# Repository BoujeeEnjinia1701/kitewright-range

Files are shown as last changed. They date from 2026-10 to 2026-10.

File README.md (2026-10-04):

# Kitewright Range

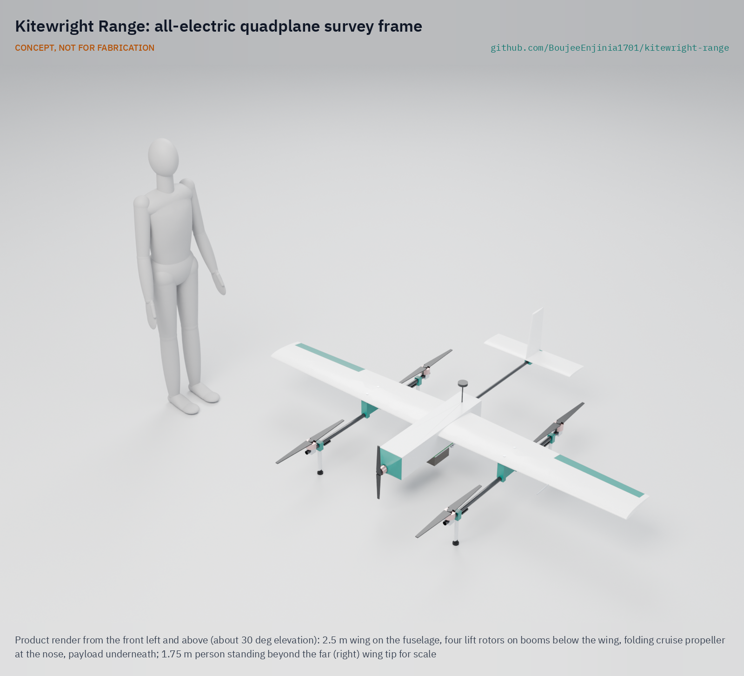
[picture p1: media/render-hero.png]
Kitewright Range: all-electric quadplane survey frame, product render


     

**Area:** Aerial robotics · **TRL:** 3 of 9 (proof of concept on paper; design constructable) · **Value-engineering target:** USD 5,000; estimated cost USD 4,314 (USD 686 under) · **Difficulty:** 4 of 5

An all-electric quadplane frame for the Kitewright family that takes off vertically and cruises on a fixed wing for long surveys.

[Problem](docs/01-problem.md) · [Precis](docs/02-concept.md) · [Requirements](docs/03-requirements.md) · [Calculations](docs/04-calcs/01-sizing.md) · [Prototype build plan](docs/05-build-plan.md) · [Design decisions](docs/06-design-decisions.md) · [General arrangement](cad/drawings/KWR-DWG-001.png) · [3D viewer](media/viewer.html)

CONCEPT, NOT FOR FABRICATION. On paper (KWR-CAL-001): 2.5 m span, 11.1 kg with a 1 kg payload, 52 % hover thrust margin at 5,000 m, and 33 min and 44 km on the wing with a 20 % reserve. Endurance and take-off mass miss their targets; Amish accepted both for the first prototype.

## Concept rationale

Kitewright Range is the long-reach frame of the Kitewright civilian drone family. It is an all-electric quadplane: four fixed lift rotors on two booms for vertical take-off and landing, a single fixed wing for cruise, and one electric cruise motor. It is not a tail-sitter and it has no tilting motors. It takes off from a moraine ridge or a lakeside camp, climbs, then flies on the wing, which needs far less power than hovering, so one battery covers a whole lake or snow basin.

It carries the Kitewright Core: an open PX4 or ArduPilot autopilot, the ColdCell power bus and the family's single payload mount (Pixhawk DS-014 style connector on a plain rail with a locking pin). Any Kitewright payload, including LakeWatch, fits without rework. Keeping the frame open and buildable means a state disaster agency, a university glaciology group or a mountain NGO can build, repair and adapt it, rather than wait for a vendor to support its altitude and climate.

## Burning platform

About 15 million people worldwide live in the path of potential glacial lake outburst floods, and 62% of them are in High Mountain Asia; since 1990 the number of glacial lakes has grown by 53% and their volume by 48% ([Taylor et al., Nature Communications, 2023](https://www.nature.com/articles/s41467-023-36033-x)). India has identified 189 high-risk glacial lakes out of about 7,500 in its Himalaya, but field teams can reach them only from June to September because they sit above 4,500 m, and only 15 had been visited when the national programme was approved ([ThePrint, 2024](https://theprint.in/india/govt-approves-rs-150-crore-for-glacial-lake-outburst-flood-risk-mitigation-programme-for-4-states/2232525/)).

Fixed-wing VTOL drones already do this kind of survey, but at a price and within limits that do not suit these users. The Quantum Systems Trinity Pro lists a 5,500 m service ceiling and a lowest operating temperature of -12 C ([Quantum Systems](https://quantum-systems.com/trinity-pro/)) and sells for about USD 23,790 ([Drone Nerds](https://www.dronenerds.com/products/quantum-systems-trinity-pro-americas)). Many Himalayan lakes lie at or above that ceiling, and air at 5,000 m in the standard atmosphere is already at -17.5 C with a density of 0.736 kg/m3, 60% of sea level ([Engineering ToolBox, US Standard Atmosphere](https://www.engineeringtoolbox.com/standard-atmosphere-d_604.html)). An open design lets users tune wing, rotors and batteries to their own altitude instead of accepting a vendor's envelope.

## Where it could be used

### By industry

| Industry | Use |
| --- | --- |
| Disaster risk management | Repeat surveys of high-risk glacial lakes and their moraine dams for state and national disaster agencies (with the LakeWatch payload) |
| Glaciology and climate research | Mapping of glacier snouts, lake area and snow cover over whole basins in one flight |
| Hydropower | Upstream hazard checks on lakes and valleys above run-of-river plants |
| Mountain search and rescue | Wide-area first sweep of a valley or glacier before a multirotor narrows the search |
| Water resources | Snowpack and melt surveys that feed seasonal water supply forecasts |

### By country or region

| Country or region | Why it matters there |
| --- | --- |
| India (Sikkim, Himachal Pradesh, Uttarakhand, Arunachal Pradesh) | The national programme covers 189 high-risk lakes, reachable on foot only from June to September above 4,500 m ([ThePrint, 2024](https://theprint.in/india/govt-approves-rs-150-crore-for-glacial-lake-outburst-flood-risk-mitigation-programme-for-4-states/2232525/)). |
| India (Kashmir Himalaya) | A 2026 inventory found 155 glacial lakes, five with very high outburst susceptibility threatening several thousand buildings, 15 major bridges and a hydropower project ([Journal of Glaciology, 2026](https://www.cambridge.org/core/journals/journal-of-glaciology/article/glacial-lake-outburst-flood-susceptibility-and-potential-downstream-implications-across-the-kas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)). |
| Pakistan (Gilgit-Baltistan and Khyber Pakhtunkhwa) | The UNDP GLOF-II project works across 24 valleys in 15 districts and serves more than 605,000 people ([UNDP](https://www.undp.org/pakistan/projects/scaling-glacial-lake-outburst-floods-risk-reduction-northern-pakistan-glof-ii-project)). |
| Nepal | The August 2024 Thame flood came from two lakes that do not appear to have been formally monitored beforehand ([Wikipedia, 2024 Thame flood](https://en.wikipedia.org/wiki/2024_Thame_flood)). |
| Peru (Cordillera Blanca) | Lake Palcacocha, whose 1941 outburst killed at least 1,600 people in Huaraz, had grown to 17.4 million m3 by 2016 and is still considered hazardous ([HESS, 2020](https://hess.copernicus.org/articles/24/93/2020/)). |

## What sparked the idea

In July 2018 the climber Rick Allen fell from an ice cliff while descending Broad Peak in the Karakoram and was missing for 36 hours. Bartek Bargiel, filming his brother's ski descent of K2, flew his drone over the slope, found Allen alive at about 7,500 m and guided a rescue team to him ([Explorersweb, 2018](https://explorersweb.com/rick-allen-found-alive-on-broad-peak/)). That flight showed what a small drone can do in the high mountains. It also showed the limit: a consumer multirotor has minutes of air time at that height. Kitewright Range asks what an open, long-reach frame could do for the same mountains, starting with the glacial lakes that threaten the valleys below.

## Problem

Surveys of glacial lakes and snowpack in the high Himalaya need a drone that takes off from rough ground and still covers many kilometres in thin, cold air. Commercial fixed-wing VTOL drones that can do this are closed and cost more than most mountain agencies and research groups can field.

Full problem statement: [docs/01-problem.md](docs/01-problem.md)

## Concept

An all-electric quadplane frame for the Kitewright family (separate fixed lift rotors, single fixed wing, electric cruise motor, not a tail-sitter) that takes off vertically and cruises for long survey flights such as glacial lakes and snowpack.

Full design precis: [docs/02-concept.md](docs/02-concept.md) · Requirements: [docs/03-requirements.md](docs/03-requirements.md)

## Key components

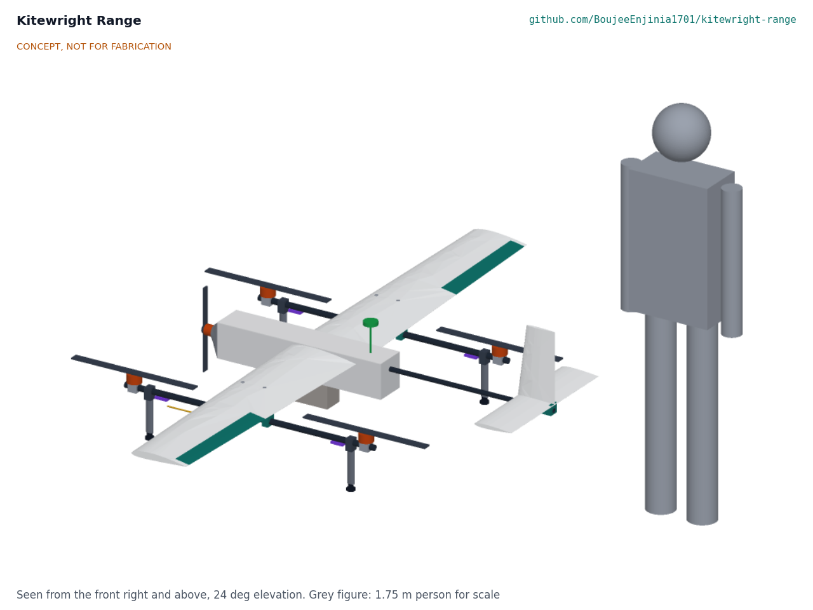
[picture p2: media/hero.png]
Concept overview with a 1.75 m person for scale


- Two-piece foam and glass wing, 2.5 m span, on a carbon joiner through a lite-ply fuselage
- Four fixed 22 in lift rotors on carbon booms, hung on printed pylons below the wing
- Tractor cruise motor with a folding propeller at the nose; conventional tail on a carbon boom
- Kitewright Core hung under the fuselage at the centre of gravity; two 6S Li-ion packs (648 Wh) with AS150 leads
- Four faired landing legs; heated pitot

## Building the prototype

The prototype is built from hot-wire cut foam skinned in glass, lite-ply, carbon tube and printed ASA parts, with bought motors, propellers and the Kitewright Core avionics. The build plan takes a capable model builder through thirteen made components and sixteen assembly steps, each with a picture. Powered work stops at five safety stops, and the lift propellers go on only once the aircraft is tied down inside a keep-out zone. It is a plan, not yet built; building to it is TRL 4 work.

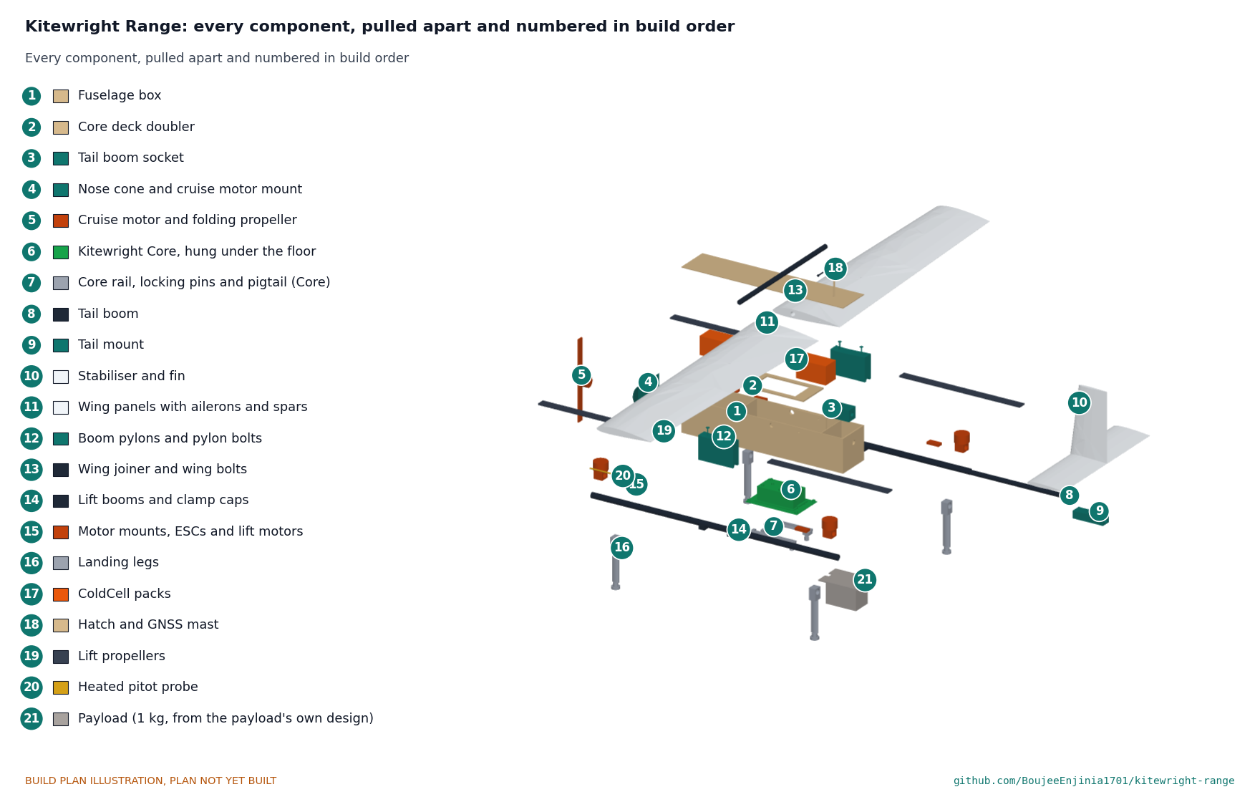
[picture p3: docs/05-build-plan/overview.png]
Every component, pulled apart and numbered in build order


## Safety

> Published as an open engineering reference, not certified aviation equipment.
>
> Civilian use only. Certification under FAA Part 107, EASA rules or India's Drone Rules 2021 is out of scope at this TRL and will be addressed if prototypes progress.
>
> Spinning lift and cruise propellers can cause serious injury; arming, pre-flight and keep-out procedures must be written before any powered test.
>
> Lithium battery packs carry fire risk, especially after a crash or cold charging; charge only between 0 and 45 °C pack temperature in a fire-resistant box, and follow ColdCell safety rules.
>
> Lift propellers are fitted only at the build plan's propeller safety stop; first hovers are tied down inside a 15 m keep-out zone with the arming plug and lockable arming switch in use.
>
> Loss of link or battery in thin air may cause a crash in remote terrain; failsafe return and landing behaviour must be set and tested.
>
> Fly only where local rules allow, away from people, aircraft and wildlife; high-altitude sites may lie in restricted border or protected areas.
>
> This design is published as an open engineering reference. It is not certified equipment.

## Repository layout

| Folder | Contents |
| --- | --- |
| `docs/` | Problem, concept, requirements, calculations and design decisions |
| `cad/src/` | build123d Python source, the source of truth for all geometry |
| `cad/step/`, `cad/stl/` | Exported models for FreeCAD, other CAD tools and printing |
| `cad/drawings/` | 2D sketches and dimensioned drawings |
| `bom/` | Bill of materials |
| `electronics/` | KiCad schematics and PCB layouts |
| `firmware/` | Microcontroller code |
| `media/` | Renders, perspectives and photos |
| `build-log/` | Dated prototyping notes |

## Documentation

Controlled documents follow the portfolio [documentation standard](.kit/STANDARDS.md). Each carries a document ID (KWR-PRC-001 for the precis), a version and a revision history. Branded PDFs are built with `python .kit/render.py` and attached to GitHub Releases when a document is tagged, for example `KWR-PRC-001/v1.0`.

## Credits

Designed by Amish Chadha at Design Molecule Labs. See [CONTRIBUTORS.md](CONTRIBUTORS.md) for roles. To cite this design, use [CITATION.cff](CITATION.cff) (GitHub shows it as "Cite this repository").

AI assistance (Claude) was used to accelerate prototype documentation and first-pass research. Design direction and all decisions are Amish Chadha's, recorded in this repository's decision records (`docs/decisions/`).

## Licenses

- **Hardware** (CAD, drawings, BOM, electronics): [CERN-OHL-S v2](LICENSE)
- **Software** (firmware, scripts, notebooks): [MIT](LICENSE-SOFTWARE)

A project of the [Design Molecule](https://designmolecule.com) lab.

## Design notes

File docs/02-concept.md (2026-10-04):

---
doc_id: KWR-PRC-001
title: Kitewright Range design precis
project: Kitewright Range
doc_type: Precis
version: "0.5"
status: Draft
date: '2026-10-04'
author: Amish Chadha
license: CERN-OHL-S-2.0
revisions:
- version: "0.1"
  date: '2026-09-30'
  author: Amish Chadha
  change: Initial scaffold
- version: "0.2"
  date: '2026-10-03'
  author: Amish Chadha
  change: TRL 2 precis with first-order numbers, components, design choices and safety (KWR-DDR-001)
- version: "0.3"
  date: '2026-10-03'
  author: Amish Chadha
  change: TRL 3 numbers from KWR-CAL-001 v0.2 on the constructable design (KWR-DDR-002)
- version: "0.4"
  date: '2026-10-03'
  author: Amish Chadha
  change: 'Numbers from KWR-CAL-001 v0.3 after Amish''s 2026-10-03 decisions (KWR-DDR-003; "i agree with all the 46 recommendations you provided. please proceed.")'
- version: "0.5"
  date: '2026-10-04'
  author: Amish Chadha
  change: 'Amish''s round-3 decision 10A (KWR-DDR-004); the Kitewright Core under the floor to the family envelope; numbers from KWR-CAL-001 v0.4'
---

# Kitewright Range design precis

An all-electric quadplane frame for the Kitewright family that takes off vertically and cruises on a fixed wing for long surveys.

## Summary

Kitewright Range is a 2.5 m span quadplane of 11.4 kg that lifts off on four fixed 22 in rotors, flies its survey on the wing and lands vertically again. On paper it hovers at 5,000 m with a 48.3 % thrust margin and flies 30.6 min and 41.5 km on the wing with a 1 kg payload and a 20 % reserve. It is built from hot-wire cut foam and glass, lite-ply, carbon tubes and printed parts with hobby tools, and costs an estimated USD 4,314 against a USD 5,000 value-engineering target. Endurance and take-off mass miss their targets; Amish accepted both for the first prototype on 2026-10-03 (KWR-DDR-003).

## How it works

A two-piece wing on a carbon joiner sits at the shoulder of a lite-ply fuselage. Under each wing a printed pylon holds a carbon boom with one lift motor 531 mm ahead of the centre of gravity and one 531 mm behind it, so the four rotors lift through the balance point; their discs run 77 mm below the wing-top plane. A tractor motor with a folding propeller at the nose drives the aircraft in cruise, and a conventional tail on a carbon boom steers it. The aircraft rises on the rotors, accelerates on the cruise motor to about 22 m/s, stops the rotors with their blades parked fore and aft, and flies a planned survey; then it slows, hovers and lands on four faired legs. The Kitewright Core hangs under the fuselage floor at the centre of gravity to the family mounting envelope, its lid up through the floor, and the payload hangs on its shoe from the Core's rail beneath it. Two ColdCell packs, one in the nose bay and one behind the Core's lid, feed the Core's power bus through AS150 plugs; the Core's GNSS receiver and antennas sit on the hatch. The flight code is stock PX4 quadplane firmware with published parameters (KWR-DDR-001, D1).

## Main components

Table 1. Components (numbers are BOM lines)

| # | Component | Made from, or bought | Role |
| --- | --- | --- | --- |
| 1, 2 | Fuselage box and hatch | Lite-ply and birch ply, glass outside | Carries the wing, packs, avionics, payload mount and tail |
| 3 | Nose cone and cruise motor mount | Printed ASA | Fairs the nose and holds the cruise motor on the thrust line |
| 4, 14, 15 | Tail boom socket, tail boom, tail mount | Printed ASA, carbon tube | Carries the tail 1 m behind the wing |
| 5, 6, 7, 8 | Wing panels with ailerons, spars, joiner, wing bolts | XPS foam and glass, carbon tubes, nylon bolts | Lift in cruise; panels come off for transport |
| 9, 10, 11, 12 | Boom pylons, pylon bolts, clamp caps, lift booms | Printed ASA, steel bolts, carbon tube | Hold the lift motors below the wing |
| 13 | Landing legs | Carbon rod, printed clamp and fairing, rubber foot | Stand the aircraft on rough ground |
| 16, 17 | Stabiliser with elevator, fin with rudder | XPS foam and glass | Pitch and yaw stability and control |
| 18 to 21 | Motor mounts, ESCs, 5215-class lift motors, 22 in propellers | Bought | Vertical take-off, hover and landing |
| 22, 23 | Cruise motor and ESC, 14 in folding propeller | Bought | Wing-borne flight |
| 24, 25 | Servos, heated pitot and airspeed sensor | Bought | Control surfaces; airspeed in cold and icing |
| 26, 27 | Kitewright Core with its payload rail | From the Kitewright Core, hung under the floor to the family envelope | Autopilot, GNSS, radios, payload interface |
| 28 | ColdCell packs, two | From the ColdCell design | 583 Wh of heated Li-ion energy |

## Numbers from the TRL 3 calculations

Table 2. Key figures (KWR-CAL-001 v0.2)

| Quantity | Value |
| --- | --- |
| Span, wing area, aspect ratio | 2.52 m, 0.709 m2, 8.9 |
| Take-off mass with 1 kg payload | 11.35 kg |
| Centre of gravity | 28.3 % of the 281 mm mean chord |
| Hover power and thrust margin at 5,000 m | 1,835 W; 48.3 % |
| Stall and cruise speed at 5,000 m | 18.1 m/s; 22.6 m/s |
| Lift-to-drag ratio in cruise | 7.2 |
| Cruise power from the packs | 676 W |
| Energy for cruise after hover, climb and reserve | 344 Wh |
| Endurance and range on the wing | 30.6 min; 41.5 km |
| Lowest structural safety factor | 2.7 (wing spar at 2.5 g) |
| Longest part for transport | 1,205 mm |
| Estimated cost | USD 4,314; value-engineering target USD 5,000 (USD 686 under) |

Assumptions are stated in KWR-CAL-001, Table 1. The most important are the maker-class thrust of the lift motors (68.7 N each at sea level for a 5215-class motor with a 22 x 7 in propeller, scaled by density) and a zero-lift drag coefficient of 0.083.

## Key design choices

All are decided under Amish's 2026-10-03 pre-approval and argued in KWR-DDR-001 and KWR-DDR-002; the propeller size and cells follow Amish's 2026-10-03 decisions (KWR-DDR-003):

- PX4 quadplane firmware, as the Kitewright Core (D1).
- Two-piece 2.5 m wing on a joiner, sized to the 1.3 m transport case (D2, C6).
- One set of 22 in lift propellers on 5215-class motors for every altitude band (D3, KWR-DDR-003).
- Tractor cruise motor at the nose with a folding propeller, conventional tail on a tail boom (D5, C1, C5).
- Lift booms on printed pylons 90 mm below the wing, motors centred on the centre of gravity (C2 to C4).
- Two ColdCell 6S3P Li-ion packs of 5.0 Ah cells either side of the joiner (D6, C7, KWR-DDR-003).
- Foam, glass, lite-ply, carbon tube and printed parts: buildable with hobby tools (D7).
- Staged powered tests, tie-downs and conservative failsafes (D9, D10).

## Patent design-arounds

From the preliminary patent, trademark and prior-art screen (not legal advice):

- All-electric, single fixed wing, fixed lift and cruise motors (no tilting thrust), to stay clear of US10343774B2 (tilting thrust, to about 2037).
- Lift booms on pylons below the wing with the rotor discs 77 mm below the wing-top plane, to stay clear of US9120560B1 (rotors even with the wing top surfaces, to 2033). The model checks this on every run.
- Layout kept distinct from US9242738B2 (Wisk, to about 2032); claims still to be read by an attorney before any sale.
- Not a tail-sitter, keeping clear of the Airbound tail-sitter noted in the family screen.

## Relationship to other lab projects

- Kitewright Core: autopilot, radios, GNSS, payload rail and power bus, used unchanged, to the Kitewright interface table of 2026-10-04 in `docs/REVIEW.md`.
- ColdCell: the two heated packs. Kitewright Lift shares the 6S bus.
- AltiRig: measures the lift motor and propeller thrust at 5,000 m density before any flight.
- LakeWatch: the first payload, within 1 kg on the Core mount.

## Safety

> **Safety:** Kitewright Range is published as an open engineering reference, not certified aviation equipment, for civilian use only. Certification under FAA Part 107, EASA rules or India's Drone Rules 2021 is out of scope at this TRL and will be addressed if prototypes progress.
>
> **Propellers.** Four 20 in lift propellers and a 14 in cruise propeller can cause serious injury. The lift propellers are fitted only at the build plan's propeller safety stop, never on the bench; a removable arming plug and a lockable arming switch keep the motors dead while anyone handles the aircraft; first hovers are tied down to ground anchors inside a 15 m keep-out zone (KWR-DDR-001, D9).
>
> **Lithium-ion packs.** Two packs hold about 580 Wh. Charge only between 0 and 45 °C pack temperature, in a fire-resistant box, never unattended; treat any pack from a crash as damaged and isolate it outdoors.
>
> **Loss of link or power in remote terrain.** Return to launch on the wing and land vertically; land in place at the reserve; fly inside a geofence (D10). Fly only where local rules allow, away from people, aircraft and wildlife; high-altitude sites may lie in restricted border or protected areas.
>
> **Structure.** The wing spar has the smallest margin (2.9 at 2.5 g). Proof-load the wing before the first flight (TRL 4).

## Open questions

None in this precis. Requirements not met or at risk are open decisions for Amish in the design decisions register (`docs/06-design-decisions.md`).

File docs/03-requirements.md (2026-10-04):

---
doc_id: KWR-REQ-001
title: Kitewright Range requirements
project: Kitewright Range
doc_type: Requirements
version: "0.5"
status: Draft
date: '2026-10-04'
author: Amish Chadha
license: CERN-OHL-S-2.0
revisions:
- version: "0.1"
  date: '2026-09-30'
  author: Amish Chadha
  change: Initial scaffold
- version: "0.2"
  date: '2026-10-03'
  author: Amish Chadha
  change: TRL 2 concept status for every requirement
- version: "0.3"
  date: '2026-10-03'
  author: Amish Chadha
  change: TRL 3 status from KWR-CAL-001 v0.2 on the constructable design; R10 cost stated against the value-engineering target
- version: "0.4"
  date: '2026-10-03'
  author: Amish Chadha
  change: 'Status from KWR-CAL-001 v0.3 after Amish''s 2026-10-03 decisions (KWR-DDR-003; Amish: "i agree with all the 46 recommendations you provided. please proceed."); targets unchanged; R2 and R7 shortfalls accepted for the first prototype'
- version: "0.5"
  date: '2026-10-04'
  author: Amish Chadha
  change: 'Status from KWR-CAL-001 v0.4 after Amish''s round-3 decision 10A (KWR-DDR-004; Amish: "For round 3, I agree with all your proposed recommendations"): the 0.99 kg Kitewright Core to the family envelope; targets unchanged'
---

# Kitewright Range requirements

Eight of the ten requirements are met on paper or by design (KWR-CAL-001 v0.4, Table 6). On 2026-10-04 Amish decided the Kitewright family reconciliation as recommended ("For round 3, I agree with all your proposed recommendations"; KWR-DDR-004): Range now carries the 0.99 kg Kitewright Core to the family mounting envelope, under the fuselage floor at the centre of gravity, with AS150 plugs on its packs. No requirement is restated. Endurance (R2) and take-off mass (R7) are not met. The targets below are unchanged. Amish decided the shortfalls on 2026-10-03 ("i agree with all the 46 recommendations you provided. please proceed."; KWR-DDR-003): 22 in propellers on 5215-class motors for R1, 5.0 Ah cells in the same two packs for R2 and R3, and the foam, glass and lite-ply airframe kept for the first prototype and weighed at TRL 4 for R7. No requirement is restated.

Table 1. Requirements and status at TRL 3

| ID | Requirement | Target | Verification (TRL 3 or later) | Status (KWR-CAL-001) |
| --- | --- | --- | --- | --- |
| R1 | Vertical take-off and landing at high altitude | Hover with at least 30% thrust margin at 0.74 kg/m3 air density (5,000 m) at maximum take-off mass | Lift motor and propeller thrust measured in AltiRig at 5,000 m density; margin calculated for the as-built mass | Met on paper: 48.3 % on maker-class thrust at 11.35 kg (22 in propellers, 5215-class motors); to measure in AltiRig |
| R2 | Cruise endurance at altitude | At least 45 min wing-borne flight at 5,000 m and -20 C with a 1 kg payload and 20% reserve (target) | Energy model checked against bench power data, then timed flight at a high site | **Not met:** 30.6 min with 5.0 Ah cells and the 0.99 kg Core under the floor; accepted for the first prototype (KWR-DDR-003) |
| R3 | Survey range | At least 40 km of survey track per flight at 5,000 m (target) | Flight log distance on a mapped survey pattern | Met on paper: 41.5 km |
| R4 | Payload capacity | 1.0 kg on the Kitewright mount within the centre of gravity range | Weigh and balance check; flight with a dummy payload | Met by design: the Core and its payload shoe under the CG, 28.3 % of the mean chord with or without the payload |
| R5 | Operating temperature | -20 to +40 C (-4 to +104 F) for all airframe electronics and servos | Cold chamber soak and function test of servos, motors and avionics | Met on paper by specification; cold ratings to confirm when parts are bought |
| R6 | Wind tolerance | Take off, transition and land in sustained wind of 10 m/s with gusts to 14 m/s | Flight tests with a logged anemometer at the launch site | Met on paper: cruise 22.6 m/s, stall 18.1 m/s, about 9 degrees of tilt holds a 14 m/s side gust in hover |
| R7 | Maximum take-off mass | No more than 8 kg including payload (target) | Weigh the complete aircraft | **Not met:** 11.35 kg; airframe kept and weighed at TRL 4 (KWR-DDR-003) |
| R8 | Transport | Packs into cases of no more than 1.3 m long; each carried load no more than 15 kg | Pack and measure; two-person carry trial | Met by design: longest part 1,205 mm; two cases of about 9 and 12.5 kg |
| R9 | Patent design-arounds held | Fixed motors, single wing, rotor discs clear of the wing-top plane in every revision | Design review checklist at each revision | Met by design: discs 77 mm below the wing-top plane, checked by the model |
| R10 | Open and buildable | All parts off the shelf or made with hobby tools; bill of materials at or below USD 5,000 | Costed BOM review; independent build by a second team | Met on paper: Value-engineering target: USD 5,000. Estimated cost of the constructable design: USD 4,314 (USD 686 under the target) |

## Requirements at risk or not met

- R2 and R7 pull against each other: more pack energy adds mass, and a lighter aircraft carries less energy. Amish accepted both shortfalls for the first prototype (KWR-DDR-003); with the reconciled Core no option inside the concept meets R2 on paper any more; a moulded carbon airframe with two 6S4P packs comes closest (42.5 min, USD 5,754) and is the second-prototype path (KWR-CAL-001 section H).
- R1 still rests on maker-class thrust that has not been measured at 5,000 m density; the 48.3 % margin leaves room for a thrust shortfall of about 12 % before the 30 % line.

## Assumptions

- Hover and cruise figures are at the ISA density for 5,000 m (0.736 kg/m3) with the ColdCell packs warmed before take-off.
- Stock PX4 quadplane firmware is enough; no custom flight control code is needed (KWR-DDR-001, D1).
- ColdCell packs deliver 95 % of their capacity at -20 °C once warmed (cross-repo assumption).
- Most survey missions can start from a site within 10 km of the target lake.

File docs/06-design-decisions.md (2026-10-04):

---
doc_id: KWR-DEC-001
title: Kitewright Range design decisions register
project: Kitewright Range
doc_type: Design decisions register
version: "0.3"
status: Draft
date: '2026-10-04'
author: Amish Chadha
license: CERN-OHL-S-2.0
revisions:
- version: "0.1"
  date: '2026-10-03'
  author: Amish Chadha
  change: Register opened at TRL 3; decisions made under the 2026-10-03 pre-approval; four requirement decisions proposed, awaiting Amish
- version: "0.2"
  date: '2026-10-03'
  author: Amish Chadha
  change: 'O1 to O4 decided by Amish on 2026-10-03 ("i agree with all the 46 recommendations you provided. please proceed."; 36B, 37A, 38A) and moved to Decisions made (KWR-DDR-003); Core power leads taken on under Core decision 33B'
- version: "0.3"
  date: '2026-10-04'
  author: Amish Chadha
  change: 'Round-3 decision 10A (Amish, 2026-10-04: "For round 3, I agree with all your proposed recommendations") recorded in Decisions made (KWR-DDR-004)'
---

# Kitewright Range design decisions register

Every design decision still to be made, and every decision made, in one place. Each decision is argued in full in its decision record under `docs/decisions/`, and the open ones in `docs/REVIEW.md` (TRL 3, Decisions for Amish); this register is the index Amish works from. The build plan (`docs/05-build-plan.md`) describes the design as it stands and does not list open decisions.

## Open decisions

None. Amish decided O1 to O4 on 2026-10-03 (KWR-DDR-003) and the Kitewright family reconciliation on 2026-10-04 (KWR-DDR-004); the design and build plan carry those decisions. R2 (30.6 min) and R7 (11.35 kg) remain not met, as accepted for the first prototype. Nothing in carrying out 10A needs Amish.

## To confirm when parts are bought

| # | What to confirm | Why it matters | Source |
| --- | --- | --- | --- |
| 1 | 5215-class lift motor thrust with a 22 x 7 in propeller at 0.736 kg/m3, measured in AltiRig | R1 rests on maker-class figures scaled by density; the 52.0 % margin allows about 14 % less thrust | KWR-CAL-001 C, KWR-DDR-003 |
| 2 | Cold ratings of the ESCs, servos, cruise motor ESC and pitot heater to -20 °C, or a cold soak test | R5 is met only by specification | KWR-REQ-001 |
| 3 | The joiner slides into both spar bores without play | The wing joint depends on it | KWR-DDR-002, C6 |
| 4 | The cruise motor's bolt circle and shaft length | They set the nose cone inserts and the propeller position | KWR-DDR-002, C5 |
| 5 | Kitewright Core avionics envelope (180 x 110 x 60 mm) and mass (0.78 kg with the mast); Core's own figure after its decision 33B is about 0.99 kg including the payload mount (Range carries 0.90 kg for the same items) | They set the front bay and the balance | Cross-repo assumption; `docs/REVIEW.md` cross-repo actions |
| 6 | ColdCell pack size (138 x 75 x 82 mm), mass (1.40 kg) with 5.0 Ah high-rate 21700 cells, and its lead (XT90 here, AS150 in the Core) | They set the battery bays, the energy and the balance | Cross-repo assumption, KWR-DDR-003 |
| 9 | Kitewright Core pad positions and grommets for the four 8 AWG power leads Range now supplies | Lead lengths and the solder joints at integration | Core decision 33B, KWR-DDR-003 |
| 7 | Payload mount plate (160 x 80 x 12 mm) and its four M4 holes | They set the floor inserts | Cross-repo assumption |
| 8 | Transport cases with at least 1,250 mm inside | The wing panel is 1,205 mm with its root fittings | KWR-CAL-001 F |

## Value engineering

Value-engineering target: USD 5,000 (a hypothetical control target, not a limit). Estimated cost of the constructable design: USD 4,293 (USD 707 under the target). Main cost drivers and savings worth trying:

- The largest lines are the Kitewright Core avionics share (USD 900, assumed), the two ColdCell packs of 5.0 Ah cells (USD 700), the four 5215-class lift motors (USD 600), the two transport cases (USD 360) and the four lift ESCs (USD 180).
- The 2026-10-03 decisions added USD 348: motors USD 120, propellers USD 40, cells USD 120, boom tubes USD 8 and the Core power leads USD 60 (moved from the Core's bill).
- Savings worth trying: soft padded bags in place of hard cases for vehicle transport (about USD 200); four-in-one ESC boards are lighter but would move power wiring into the fuselage, so they are not recommended.

## Decisions made

| Date | Decision | Decided by | Record |
| --- | --- | --- | --- |
| 2026-10-03 | TRL 2 review decisions D1 to D10: PX4; 2.5 m two-piece wing; one 20 in propeller set; winch on Lift; nose tractor and tail boom; two ColdCell 6S3P packs; foam, ply and printed build; Sikkim State Disaster Management Authority as first co-design candidate (not agreed); staged powered tests; conservative failsafes | Amish: "start with the first 14 repos from the list of 29 projects. I pre-approve the batch runs along with any recommendations you come up with. I also accept any cost overruns or variations from the assumed scope cost." and "Proceed with the remaining 15 scaffolds" | KWR-DDR-001 |
| 2026-10-03 | Design for construction C1 to C13: tail boom, pylons, boom spacing, motors on the centre of gravity, nose tractor, joiner and wing bolts, fuselage bays, landing legs, wing conduits, payload mount, tail joint, hatch, pitot | Amish, same pre-approval | KWR-DDR-002 |
| 2026-10-03 | O1 (36B), R1: 22 in propellers on 5215-class motors, booms 50 mm longer and 20 mm further out; hover margin 52.0 % | Amish: "i agree with all the 46 recommendations you provided. please proceed." | KWR-DDR-003 |
| 2026-10-03 | O2 and O3 (37A), R2 and R3: 5.0 Ah cells in the same two 6S3P packs; 32.9 min and 44.3 km with O1-B | Amish, same words | KWR-DDR-003 |
| 2026-10-03 | O4 (38A), R7: keep the foam, glass and lite-ply airframe and weigh it at TRL 4; 11.07 kg | Amish, same words | KWR-DDR-003 |
| 2026-10-03 | Range supplies the four Kitewright Core power leads with AS150 plugs (Core decision 33B) | Amish, same words (Core decision 33B) | KWR-DDR-003 |
| 2026-10-04 | Round-3 decision 10A: AS150 plugs on the packs (XT90 before); the Kitewright Core to the one family mounting envelope, the Core's drawing the reference: hung under the floor at the centre of gravity on four M4 (220 x 130 mm) in a 6 mm birch doubler, lid up through a 200 x 112 mm opening, fuselage 156 mm wide (150 inside), packs moved to the nose bay and behind the lid, rear bulkhead at 645 mm, GNSS and antennas on the hatch; Range recomputed with the 0.99 kg Core (30.6 min, 41.5 km, 48.3 %); the Kitewright interface table in `docs/REVIEW.md` | Amish: "For round 3, I agree with all your proposed recommendations" | KWR-DDR-004 |

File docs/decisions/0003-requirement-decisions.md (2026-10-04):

---
doc_id: KWR-DDR-003
title: Kitewright Range requirement decisions (R1, R2, R3, R7) and Core power leads
project: Kitewright Range
doc_type: Design decision record
version: "0.1"
status: Draft
date: '2026-10-03'
author: Amish Chadha
license: CERN-OHL-S-2.0
revisions:
- version: "0.1"
  date: '2026-10-03'
  author: Amish Chadha
  change: Amish's requirement decisions 36B, 37A and 38A carried out, with the Kitewright Core power leads taken on under Core decision 33B
---

# 0003: Requirement decisions on hover margin, endurance, range and mass

- **Date:** 2026-10-03
- **Status:** accepted
- **Decided by:** Amish Chadha, 2026-10-03, accepting every recommendation put to him in the second round of requirement decisions: "i agree with all the 46 recommendations you provided. please proceed." For Kitewright Range: 36B (R1, register O1), 37A (R2 and R3, register O2 and O3) and 38A (R7, register O4). Kitewright Core decision 33B, decided in the same words, moves the Core's power leads to each frame.

> **Safety:** The 22 in lift propellers are larger and the motors stronger: fit them only at the propeller safety stop of the build plan, with the arming plug out and the lockable switch locked, and hold the 15 m keep-out zone for tied first hovers (KWR-DDR-001, D9). The 5.0 Ah cells change nothing in the ColdCell pack's charging rules: charge between 0 and 45 °C pack temperature in a fire-resistant box. Soldering the 8 AWG Core power leads needs a 100 W iron; hold the wire with pliers, and check polarity and the opposite-gender plugs with a meter before any pack is connected.

## Context

At TRL 3 (KWR-CAL-001 v0.2) four requirements were at risk or not met: R1 hover thrust margin (31.8 % on unmeasured maker-class thrust), R2 endurance (31.0 min against 45 min), R3 survey range (40.9 km against 40 km) and R7 take-off mass (10.58 kg against 8 kg). Each was put to Amish in `docs/REVIEW.md` as state, options and a recommendation, and listed as O1 to O4 in `docs/06-design-decisions.md`.

In parallel, Kitewright Core decision 33B lightens the core by moving its four 8 AWG power leads and AS150 plugs out of the core and into each frame's harness, so Range now supplies its own.

## Options considered

- **R1 (decision 36, O1):** A: keep 20 in propellers on 5212-class motors. B (chosen): 22 in propellers on 5215-class motors, booms 50 mm longer and 20 mm further out. C: keep A and change only if AltiRig measures under the target.
- **R2 and R3 (decision 37, O2 and O3):** A (chosen): two 6S3P packs of 5.0 Ah cells. B: two 6S4P packs. C: moulded carbon airframe with two 6S4P packs. Range option A was the same cell change; with 36B it is the combination v0.2 listed as option B for R3.
- **R7 (decision 38, O4):** A (chosen): keep the foam, glass and lite-ply airframe and weigh it at TRL 4. B: moulded carbon wing, tail and fuselage. C: fly one pack.

## Decision

1. **36B.** Lift motors are 5215-class (about 285 g, 62 mm can, at least 7.0 kgf maker static thrust with a 22 x 7 in propeller on 6S, USD 150 each) on mounts with a top plate at least 64 mm across; lift propellers are 22 x 7 in carbon (about 55 g, USD 50 each). The booms move from 470 to 490 mm from the centre line and the motors from 506 to 531 mm ahead of and behind the centre of gravity, so each boom is 1,142 mm (cut from a 1,200 mm tube) in place of 1,092 mm.
2. **37A.** Both ColdCell packs stay 6S3P, 138 x 75 x 82 mm and 1.40 kg, with high-rate 21700 cells of 5.0 Ah: 324 Wh each (USD 350 each, USD 60 more).
3. **38A.** The airframe is unchanged. R7 stays not met for the first prototype; the aircraft is weighed at TRL 4 and the target is reviewed against the first site's rules before a second prototype.
4. **Core power leads (Core 33B).** Range supplies the four 8 AWG power leads with AS150 plugs (two pack inputs, two frame outputs, opposite genders), soldered to the Core's pads at integration: BOM line 33, about 124 g, USD 60 (the Core's former BOM line 21).

No requirement target is restated.

## Results (KWR-CAL-001 v0.3)

| Requirement | Before | After | Status |
| --- | --- | --- | --- |
| R1, hover thrust margin at 5,000 m (at least 30 %) | 31.8 % at 10.58 kg | 52.0 % at 11.07 kg | Met on paper; thrust to measure in AltiRig |
| R2, endurance (at least 45 min) | 31.0 min | 32.9 min | Not met; accepted for the first prototype |
| R3, survey range (at least 40 km) | 40.9 km | 44.3 km | Met on paper |
| R7, take-off mass (no more than 8 kg) | 10.58 kg | 11.07 kg | Not met; weighed at TRL 4 |
| R9, discs below the wing-top plane (at least 70 mm) | 81 mm | 77 mm | Met by design |
| R10, cost | USD 3,945 | USD 4,293 | Met on paper |

The recommendations quoted 53.3 % and 35.6 min, 46.8 km for the options taken one at a time. Taken together, and with the Core power leads (0.12 kg) and slightly more drag from the larger motors, the figures are 52.0 %, 32.9 min and 44.3 km.

Value-engineering target: USD 5,000. Estimated cost of the constructable design: USD 4,293 (USD 707 under the target). Take-off mass 11.07 kg with the 1 kg payload (0.49 kg more: motors and propellers 0.36 kg, booms 0.01 kg, Core power leads 0.12 kg).

## Consequences

- The model (`cad/src/model.py`) gained three checks for the larger discs: at least 50 mm from the fuselage side (141 mm), at least 50 mm from the stabiliser (110 mm), and a motor no wider than its mount plate. All 72 solids in 48 parts pass; the lift and cruise discs are 33 mm apart (rule 20 mm).
- STEP and STL, the general arrangement (KWR-DWG-001 Rev P3), the concept blueprint (KWR-DWG-010 Rev P3), the concept media, the making sketches of the wing panel, pylon and boom, and the build plan overview, joints and steps are regenerated.
- The R2 and R7 shortfalls remain. A moulded carbon airframe with two 6S4P packs meets R2 on paper (45.6 min, USD 5,733) and stays the second-prototype path.
- Cross-repo: the ColdCell pack format now uses 5.0 Ah cells; Kitewright Core no longer supplies the power leads.

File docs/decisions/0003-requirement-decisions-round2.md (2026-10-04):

---
doc_id: KWR-DDR-003
title: Kitewright Range requirement decisions, round 2
project: Kitewright Range
doc_type: Design decision record
version: "0.1"
status: Draft
date: '2026-10-03'
author: Amish Chadha
license: CERN-OHL-S-2.0
revisions:
- version: "0.1"
  date: '2026-10-03'
  author: Amish Chadha
  change: Decisions O1 to O4 on the requirements not met or at risk, decided by Amish on 2026-10-03 and carried into the model, calculations, BOM and build plan
---

# 0003: Requirement decisions, round 2

- **Date:** 2026-10-03
- **Status:** Decided. Decided by Amish Chadha, 2026-10-03: "i approve all of the 47 recommendations provided by you. Execute them." Each decision below is the recommendation as worded in `docs/06-design-decisions.md` (KWR-DEC-001 v0.1), including its conditions.

## Context

KWR-CAL-001 v0.2 left four requirements not met or at risk on the constructable design: hover thrust margin (R1, 31.8 % on unmeasured maker-class thrust), endurance (R2, 31.0 min), survey range (R3, 40.9 km, a 2 % margin) and take-off mass (R7, 10.58 kg). They were set out as O1 to O4, Proposed, awaiting Amish, with options and a recommendation each. O3 was linked to the others: its recommendation was A, decided together with O2, and B if O1-B was chosen.

## Decision

Table 1. Decisions

| # | Requirement | Option chosen | Effect on the design (KWR-CAL-001 v0.3) | Condition |
| --- | --- | --- | --- | --- |
| O1 | R1, hover thrust margin | **B:** 22 in propellers on 5215-class motors | Booms 20 mm further out (490 mm from the centre line) and 50 mm longer (1,142 mm); motors 531 mm ahead of and behind the centre of gravity; margin 31.8 % to 53.4 %; +0.39 kg; +USD 160 (motors, propellers, longer boom tubes) | Thrust is a maker-class estimate (7.0 kgf at sea level) until AltiRig measures it at 0.736 kg/m3 (TRL 4) |
| O2 | R2, endurance | **A:** two 6S3P packs of 5.0 Ah high-rate 21700 cells | Pack energy 583 Wh to 648 Wh, pack mass unchanged; +USD 120. With O1-B the endurance is 33.6 min (35.6 min with O2-A alone) | R2 is still not met; C (moulded carbon airframe with 6S4P packs) was named as the path for a second prototype once the first one's drag and mass are measured |
| O3 | R3, survey range | **B**, the combined effect: the recommendation was A, decided together with O2, becoming B because O1-B is chosen | 45.0 km (the option stated about 45.0 km); +USD 280 and +0.40 kg combined with O1-B and O2-A (calculated: +USD 280, +0.39 kg). No change of its own: it is the result of O1-B with O2-A | None beyond those of O1 and O2 |
| O4 | R7, take-off mass | **A:** keep the foam, glass and lite-ply airframe | No change to the airframe. Take-off mass is now 10.97 kg (10.58 kg before O1-B) | The first prototype is weighed at TRL 4; R7 stays not met. If the 8 kg target reflects a regulatory class at the first site, that site's rules set the target before the second prototype |

## Consequences

- Requirement status (KWR-REQ-001 v0.4): R1 at risk to met on paper; R2 not met (31.0 to 33.6 min); R3 at risk to met on paper (45.0 km, a 12 % margin); R7 not met (10.58 to 10.97 kg), kept by decision. No requirement was restated.
- Estimated cost: USD 3,945 to USD 4,225 against the USD 5,000 value-engineering target (USD 775 under). `budget_usd` in `project.yaml` is the value-engineering target and stays at USD 5,000.
- The wing spar's safety factor falls from 2.9 to 2.8 at 2.5 g with the heavier aircraft; the lift boom's from 10.8 to 8.4 and the pylon bolts' from 12.5 to 9.9 with the larger thrust. All stay above 2.
- Geometry: rotor discs 78 mm below the wing-top plane (rule 70 mm), lift discs 33 mm clear of the cruise propeller disc, rear discs 110 mm ahead of the stabiliser. The model's constructability checks pass (72 solids in 48 parts).
- Regenerated from the changed model: STEP and STL, general arrangement KWR-DWG-001 Rev P3, making sketches KWR-DWG-105, 106, 108 and 109 at Rev P2, the build plan pictures, the concept media with blueprint KWR-DWG-010 Rev P3, and `media/model.glb`.
- The remaining endurance shortfall (R2) is a new open decision, O5, in `docs/06-design-decisions.md`.
- Cross-repo: ColdCell needs the 5.0 Ah cell variant of its 6S3P pack; AltiRig's first job is now the 5215-class motor with a 22 in propeller.
- Following Kitewright Core decision 17 B (not a decision of this record), the Core's four 8 AWG power leads with AS150 plugs (two pack inputs, two frame outputs) are now part of Range's harness, BOM line 29: +USD 60 and +0.124 kg, priced as on Kitewright Lift. With them the take-off mass is 11.09 kg (R7 not met), hover margin 51.7 %, endurance 32.9 min, range 44.4 km and the estimated cost USD 4,285 (KWR-CAL-001 v0.4).

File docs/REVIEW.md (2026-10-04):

# Review note: Kitewright Range

## Session 2026-09-30: scaffolded

### What was done

- Repository created from kit 1.6.0 at TRL 1, target TRL 2.
- `docs/01-problem.md` (KWR-PRB-001 v0.1): problem with cited evidence, users, environment, constraints, prior work, open questions.
- `docs/02-concept.md` (KWR-PRC-001 v0.1): how it works, components, patent design-arounds, shared blocks, safety.
- `docs/03-requirements.md` (KWR-REQ-001 v0.1): 10 proposed requirements.
- `README.md` with concept rationale, burning platform, where it could be used, and what sparked the idea.

### Next

- Run `/populate` to bring the repo to a strong TRL 2 with concept media.

## Session 2026-10-03: TRL 2 (populate, under Amish's pre-approval)

Run as the first half of `/to-trl3` on kit 1.7.0, under Amish's 2026-10-03 instructions: "start with the first 14 repos from the list of 29 projects. I pre-approve the batch runs along with any recommendations you come up with. I also accept any cost overruns or variations from the assumed scope cost." and, for Batch 2, "Proceed with the remaining 15 scaffolds".

### What was done

- Kit 1.7.0 installed (`.kit/`, `.claude/commands/`); root `CLAUDE.md` replaced from `.kit/CLAUDE.md`.
- `docs/01-problem.md` (KWR-PRB-001 v0.2): open questions answered, value-engineering wording, co-design candidate, safety note.
- `docs/03-requirements.md` (KWR-REQ-001 v0.2): concept status for each requirement (targets unchanged).
- `docs/02-concept.md` (KWR-PRC-001 v0.2): how it works, components, first-order numbers, design choices, safety.
- `docs/decisions/0001-trl2-review-decisions.md` (KWR-DDR-001): D1 to D10.
- Massing model, concept media and BOM, then carried straight into TRL 3 (below), so the TRL 2 media were superseded by the TRL 3 set in the same session.

### Results at TRL 2

- The TRL 2 concept was carried straight into the TRL 3 calculations in the same session; all figures are the TRL 3 figures below.

### Decisions made under the pre-approval (KWR-DDR-001)

- D1 PX4 quadplane firmware; D2 2.5 m two-piece wing; D3 one 20 in propeller set; D4 the LakeWatch winch belongs on Kitewright Lift; D5 nose tractor and tail boom; D6 two ColdCell 6S3P Li-ion packs; D7 foam, glass, lite-ply and printed build; D8 Sikkim State Disaster Management Authority as the first co-design candidate to approach (not agreed), a university glaciology group second; D9 staged powered tests with tie-downs, keep-out zone, arming plug and lockable switch (conservative; relax the tie-down only after 10 logged tied hovers with no fault); D10 return to launch and land vertically on loss of link or low battery, land in place at the reserve, geofence.

### Safety concerns

- Large propellers, lithium-ion packs and a crash in remote terrain; covered in the precis safety section and D9, D10.

## Session 2026-10-03: TRL 3 (advance, design for construction, build plan)

### What was done

- `docs/04-calcs/01-sizing.md` (KWR-CAL-001 v0.2) with `docs/04-calcs/sizing.py` and `results.csv`: mass and balance from the model, drag build-up, hover at 5,000 m, energy, structure, geometry rules, cost, options for every shortfall, and a results table against every requirement.
- `cad/src/model.py`: parametric build123d model of the constructable design with constructability checks (72 solids in 48 parts: no overlaps, nothing floating, rotor discs at least 70 mm below the wing-top plane, lift and cruise discs apart, every part shorter than a 1.3 m case). STEP in `cad/step/` (assembly, fuselage, right wing panel, right boom pylon, landing leg parts, tail) and STL of the printed parts in `cad/stl/`.
- `cad/src/sheets.py`: general arrangement KWR-DWG-001 at Rev P2 (P1 preliminary GA, P2 design for construction).
- `bom/bom.csv`: 32 lines, every one priced, with a supplier type.
- `cad/src/concept_media.py`: hero, cutaway, exploded view with BOM numbers, blueprint KWR-DWG-010 Rev P2, glTF viewer (`media/model.glb`, about 1 MB, coarse tessellation) and energy flow per flight.
- `docs/decisions/0002-design-for-construction.md` (KWR-DDR-002): changes C1 to C13.
- `cad/src/build_plan_media.py`: overview, 13 making sketches (KWR-DWG-101 to 113), 8 joint close-ups, 16 assembly steps.
- `docs/05-build-plan.md` (KWR-BLD-001), `docs/06-design-decisions.md` (KWR-DEC-001).
- `cad/src/product_model.py` (appearance model, hero, exploded and detail views) and render scenes exported to `/home/claude/renders/kitewright-range/` for the photoreal renders on Amish's Mac.
- `docs/02-concept.md` v0.3 and `docs/03-requirements.md` v0.3 brought to the TRL 3 figures; `project.yaml` at TRL 3, target 3, `design_state: constructable`; README leads with `media/render-hero.png` (made on the Mac) and has the build plan link and "Building the prototype".

### Results (KWR-CAL-001 v0.2)

| Quantity | Value |
| --- | --- |
| Take-off mass with 1 kg payload | 10.58 kg (packs 2.80 kg) |
| Centre of gravity | 28.4 % of the mean chord, unchanged by the payload |
| Hover at 5,000 m | 1,815 W; thrust margin 31.8 % |
| Cruise | 21.9 m/s, L/D 7.5, 585 W |
| Endurance and range on the wing | 31.0 min, 40.9 km with a 20 % reserve |
| Lowest structural safety factor | 2.9, wing spar at 2.5 g |
| Cost | Value-engineering target: USD 5,000. Estimated cost of the constructable design: USD 3,945 (USD 1,055 under the target) |

### Requirements not met or at risk

- R1 hover thrust margin: at risk (31.8 %, on maker-class thrust not yet measured).
- R2 endurance: not met (31.0 min).
- R3 survey range: at risk (40.9 km).
- R7 take-off mass: not met (10.58 kg).
- All others met on paper or by design; R5 depends on cold ratings to confirm when parts are bought.

### Decisions for Amish

Each item is **Proposed, awaiting Amish**, and is listed in `docs/06-design-decisions.md` under Open decisions. Figures are from KWR-CAL-001 v0.2, Table 5; the design stays as it is until Amish decides.

**O1. R1 hover thrust margin.** State: 31.8 % at 10.58 kg and 0.736 kg/m3, against the requirement's margin; cause: it rests on a maker-class 5.8 kgf sea-level thrust scaled by density, with no measured data, so a few percent of thrust shortfall or mass growth erases it.
- A: keep 20 in propellers on 5212-class motors. Margin 31.8 %; no cost or mass change.
- B: 22 in propellers on 5215-class motors. Margin 53.3 %; +USD 160; +0.40 kg; endurance -1.7 min, range -1.7 km; booms 50 mm longer and 20 mm further out to keep the disc clearances.
- C: keep A now and switch to B only if AltiRig measures less than the requirement. No change now; the risk moves to the test.
- **Recommendation: B.** Hover authority at 5,000 m is the aircraft's safety margin in gusts, so the conservative choice applies; the cost is small and combined with O2-A the endurance still improves on today's design.

**O2. R2 endurance.** State: 31.0 min against the requirement; cause: 583 Wh in 2.80 kg of packs drives a 10.6 kg aircraft with a zero-lift drag coefficient of 0.077 (stopped lift motors and an external payload), needing 585 W in cruise.
- A: two 6S3P packs of 5.0 Ah high-rate 21700 cells. 35.6 min; +USD 120; no mass change; hover margin unchanged.
- B: two 6S4P packs. 38.9 min; +USD 190; +0.88 kg; hover margin falls to 21.7 % (R1 then fails).
- C: moulded carbon wing, tail and fuselage with two 6S4P packs. 43.3 min; +USD 1,390; +0.19 kg; margin 29.4 %; USD 5,335 in all.
- **Recommendation: A** for the first prototype; C is the path for a second prototype once the first one's drag and mass are measured.

**O3. R3 survey range.** State: 40.9 km against the requirement, a 2 % margin; cause: range follows endurance at 21.9 m/s.
- A: 5.0 Ah cells as O2-A. 46.8 km; +USD 120; no mass change.
- B: A together with O1-B. 45.0 km; +USD 280; +0.40 kg.
- C: keep as is. 40.9 km; no change.
- **Recommendation: A**, decided together with O2 (B if O1-B is chosen).

**O4. R7 take-off mass.** State: 10.58 kg against the requirement; cause: ColdCell packs 2.80 kg, lift system with mounts 1.32 kg, payload 1.00 kg and Core avionics 0.78 kg leave 4.7 kg for an airframe built with hobby methods.
- A: keep the foam, glass and lite-ply airframe. 10.58 kg; no change.
- B: moulded carbon wing, tail and fuselage. 9.89 kg; +USD 1,200 (USD 5,145 in all, USD 145 over the value-engineering target); endurance +4.1 min.
- C: fly with one pack. 9.18 kg; endurance 15.0 min, which fails R2 and R3 by far.
- **Recommendation: A** for the first prototype, weighed at TRL 4. No option inside the concept reaches the target without giving up endurance; if the target reflects a regulatory class at the first site, that site's rules should set the target before the second prototype.

### Decisions made under the pre-approval

- KWR-DDR-001 D1 to D10 (TRL 2 review) and KWR-DDR-002 C1 to C13 (design for construction), both dated 2026-10-03 and recorded in `docs/06-design-decisions.md` with Amish's words.

### Design changes made for construction (KWR-DDR-002)

- C1 tail on its own carbon tail boom, not on the lift booms.
- C2 lift booms on printed pylons through-bolted under the wing with clamp caps; rotor discs 81 mm below the wing-top plane.
- C3 booms 470 mm out, 38 mm clear of the cruise propeller disc.
- C4 lift motors 506 mm ahead of and behind the centre of gravity.
- C5 tractor cruise motor at the nose on a printed cone, folding propeller.
- C6 two wing panels on a carbon joiner, nylon wing bolts, straight spar at 30 % chord.
- C7 lite-ply fuselage box with packs either side of the joiner and Core avionics in front.
- C8 four faired landing legs.
- C9 wing wiring conduits and root plugs.
- C10 payload mount on the centre of gravity.
- C11 printed tail socket and tail mount.
- C12 hatch with GNSS mast and arming switch.
- C13 heated pitot in the left wing.

### Build plan findings

- The concept's booms could not carry the tail and still fit the 1.3 m case (C1).
- Without a pylon depth rule, the rotor discs would sit near the wing plane the design-around avoids; the model now checks the 70 mm rule on every run.
- The boom spacing first tried (450 mm) put the front lift discs within 18 mm of the cruise propeller disc; 470 mm gives 38 mm.
- Weighing every made part from the model raised the take-off mass from the TRL 2 estimate to 10.58 kg; printed parts are weighed as walls plus infill, and the pylons were shortened to 160 mm to save 0.2 kg.
- The tightest structural margin is the wing spar (2.9 at 2.5 g); the build plan's safety stop 4 requires a proof load before free flight (TRL 4).

### Appearance model (product_model.py)

- Every part comes from `model.py`. The only difference: the lift and cruise propellers are drawn as tapered blades in place of the model's flat blade envelopes of the same diameter. Proposed, awaiting Amish (appearance only).
- The detail view should be rendered with `--focus` on the left front lift motor and pylon.
- Hero framing: the 1.75 m person stands beyond the right wing tip, behind the aircraft as seen from the hero camera, so it never stands between the camera and the product.

### Safety concerns

- Four 20 in lift propellers and a 14 in cruise propeller: fitted only at the propeller safety stop, arming plug and lockable switch, tied first hovers in a 15 m keep-out zone (D9).
- About 580 Wh of Li-ion: charge between 0 and 45 °C pack temperature in a fire-resistant box; crash-damaged packs isolated outdoors.
- Loss of link or power in remote terrain: return on the wing and land vertically, land in place at the reserve, geofence (D10).
- Wing spar margin 2.9 at 2.5 g: proof-load before free flight.
- High-altitude sites may lie in restricted border or protected areas; fly only with the site partner's permissions.

### Cross-repo actions (sibling repos not edited)

Kitewright Core and Kitewright Lift are being done in parallel; these shared-interface assumptions are used here and should be confirmed in those repos:

1. **Kitewright Core, firmware:** PX4 (VTOL standard quadplane) as the family reference, with a Range parameter set at sea level, 3,000 m and 5,000 m.
2. **Kitewright Core, avionics envelope:** 180 x 110 x 60 mm, 0.70 kg, plus a GNSS mast of 0.08 kg through the hatch; USD 900 as Range's share in the BOM.
3. **Kitewright Core, payload mount:** a 160 x 80 x 12 mm plate with a rail, locking pin and DS-014 connector, 0.12 kg, fixed by four M4 bolts; payload envelope 150 x 90 x 100 mm and 1 kg with its centre of gravity under the mount centre; connector lead through the fuselage floor.
4. **Kitewright Core, power:** a 6S bus (21.6 V nominal Li-ion) taking two packs in parallel, carrying about 85 A in hover at 5,000 m (about 42 A per pack); an arming plug in the main lead and a lockable arming switch.
5. **ColdCell:** a 6S3P pack of 4.5 Ah 21700 cells, 291.6 Wh, 1.40 kg, 138 x 75 x 82 mm, XT90 lead, film heater and BMS thermostat holding the cells above 15 °C, 95 % usable at -20 °C ambient once warmed; a 5.0 Ah cell variant is proposed in O2.
6. **Kitewright Lift:** shares the 6S bus voltage, the Core mount and the ColdCell pack format; the LakeWatch sampling winch is assigned to Lift (D4).
7. **AltiRig:** first job is the thrust of a 5212-class motor with a 20 x 6.5 in propeller (and the 5215-class with 22 in, for O1) at 0.736 kg/m3.

### Recommended next step

- Amish decides O1 to O4. Then render the hero, exploded and detail views on the Mac from the exported scenes, make the cards, and run the release gate. The design is ready for TRL 4 parts purchase and AltiRig thrust tests once O1 is settled; that is a recommendation only, not started.

## 2026-10-03: photoreal renders

Rendered with Blender Cycles on Amish's Mac from `cad/src/product_model.py`; captioned with `.kit/photo_caption.py`; `media/card.png` and `media/social-preview.png` made with `.kit/cards.py`. Views: hero, exploded, detail. image_qc passes and `render.py --check` has no FAIL.

## 2026-10-03: Amish's requirement decisions carried out

Amish Chadha, 2026-10-03: "i agree with all the 46 recommendations you provided. please proceed." For Kitewright Range that is 36B (O1, R1), 37A (O2 and O3, R2 and R3) and 38A (O4, R7); with Kitewright Core decision 33B, Range now supplies its own power leads from the frame to the Core. Recorded in `docs/decisions/0003-requirement-decisions.md` (KWR-DDR-003) and `docs/06-design-decisions.md` v0.2.

### Changes made

- **36B, R1:** 5215-class lift motors (about 285 g, 62 mm can, at least 7.0 kgf with 22 x 7 in propellers, USD 150 each) and 22 x 7 in carbon propellers (about 55 g, USD 50 each); motor mount top plate at least 64 mm across. Booms moved from 470 to 490 mm out and motors from 506 to 531 mm either side of the centre of gravity; booms 1,142 mm (were 1,092 mm), cut from 1,200 mm tube (USD 52 each). New result: **hover margin 52.0 %** at 5,000 m (target at least 30 %; met on paper, thrust still to measure in AltiRig).
- **37A, R2 and R3:** 5.0 Ah high-rate 21700 cells in the same two 6S3P ColdCell packs, 324 Wh each, same 1.40 kg (USD 350 each). New results: **endurance 32.9 min** (target 45 min; not met, accepted for the first prototype) and **range 44.3 km** (target 40 km; met on paper).
- **38A, R7:** airframe unchanged. New result: **take-off mass 11.07 kg** (target 8 kg; not met, weighed at TRL 4).
- **Core power leads (Core 33B):** new BOM line 33, four 8 AWG leads with AS150 plugs, soldered to the Core's pads at integration (about 124 g, USD 60, the Core's former BOM line 21); build plan step 4 and the bought-parts table say how.
- The recommended figures were quoted one option at a time (53.3 %; 35.6 min and 46.8 km). Taken together, with the leads (0.12 kg) and the larger motors' drag, they are 52.0 %, 32.9 min and 44.3 km. This is the combination v0.2 listed as R3 option B (45.0 km), less the leads.
- `cad/src/model.py`: three new checks (lift disc at least 50 mm from the fuselage side, 141 mm; at least 50 mm from the stabiliser, 110 mm; motor no wider than the mount plate). All 72 solids in 48 parts pass; discs 77 mm below the wing-top plane (rule 70 mm); lift and cruise discs 33 mm apart (rule 20 mm). STEP and STL regenerated.
- `docs/04-calcs/sizing.py` and `01-sizing.md` (KWR-CAL-001 v0.3), `results.csv`; `docs/03-requirements.md` v0.4 (status only; no requirement restated); `docs/05-build-plan.md` v0.2; `docs/02-concept.md` v0.4 and the README figures brought to v0.3 numbers; `bom/bom.csv`.

### Results (KWR-CAL-001 v0.3)

| Requirement | Before | After | Status |
| --- | --- | --- | --- |
| R1 hover margin (at least 30 %) | 31.8 % | 52.0 % | Met on paper |
| R2 endurance (at least 45 min) | 31.0 min | 32.9 min | Not met (accepted) |
| R3 range (at least 40 km) | 40.9 km | 44.3 km | Met on paper |
| R4 balance | 28.4 % MAC | 27.5 % MAC | Met by design |
| R7 take-off mass (8 kg or less) | 10.58 kg | 11.07 kg | Not met (accepted) |
| R9 discs below wing-top plane | 81 mm | 77 mm | Met by design |
| R10 cost | USD 3,945 | USD 4,293 | Met on paper |

Value-engineering target: USD 5,000. Estimated cost of the constructable design: USD 4,293 (USD 707 under the target). Mass 11.07 kg with the 1 kg payload (0.49 kg more). Lowest structural safety factor 2.8 (wing spar at 2.5 g); lift boom 8.4 with the stronger motors.

### Pictures changed

- General arrangement KWR-DWG-001 Rev P3; concept blueprint KWR-DWG-010 Rev P3; hero, cutaway, exploded, flow and the glTF viewer.
- Build plan: overview, making sketches KWR-DWG-105 (hardpoints at 490 mm), KWR-DWG-106 (pylon), KWR-DWG-108 (boom 1,142 mm) and the other sheets regenerated from the same model, the boom joints (joint-02 to joint-04) and assembly steps 8 to 16.

### Appearance model

- `cad/src/product_model.py` takes the 22 in propellers, larger motors and longer booms from `model.py`; the tapered blades are widened in proportion (46 mm root chord, was 42 mm). Appearance only; still recorded as proposed, awaiting Amish, with the earlier blade note. Render scenes re-exported to `/home/claude/renders/kitewright-range/` (hero, exploded, detail); the photoreal renders on the Mac need redoing to show the larger propellers.

### Open decisions

None. No new question needs Amish.

### Safety

- Larger propellers and stronger motors: fitted only at the propeller safety stop, arming plug out, tied first hovers in the 15 m keep-out zone (D9). Boom bending safety factor at full sea-level thrust is 8.4.
- The 8 AWG Core power leads: 100 W iron, pliers on hot wire, polarity checked with a meter and opposite-gender plugs before any pack is connected.
- Packs: unchanged rules; charge between 0 and 45 °C pack temperature in a fire-resistant box.

### Cross-repo actions (sibling repos not edited)

1. **ColdCell:** the Range pack is now 6S3P of high-rate 5.0 Ah 21700 cells, 324 Wh, same 138 x 75 x 82 mm and 1.40 kg, about 14 A per cell in hover at 5,000 m (USD 350 assumed).
2. **Kitewright Core:** Range supplies the four 8 AWG leads with AS150 plugs (PACK 1, PACK 2, FRAME A, FRAME B); the Core's build plan step 9 and BOM line 21 move to the frames. Core should state the pad positions and grommets the leads pass.
3. **Kitewright Core, mass:** Range carries 0.90 kg for the Core avionics, GNSS mast and payload mount (0.70, 0.08 and 0.12 kg); the Core's own estimate after 33B is about 0.99 kg for the same set. If it holds, Range gains about 0.09 kg: hover margin about 50.8 %, endurance about 0.3 min less; nothing changes status. The Core's deck interface (four M4 on 220 x 130 mm, 200 x 112 mm lid opening) also differs from the 180 x 110 x 60 mm envelope assumed here; to settle when the family interface is frozen.
4. **Pack connector:** Range's ColdCell packs have XT90 leads; the Core's inputs are AS150. Recommend AS150 on the ColdCell packs family-wide so the Range harness needs no adapters.
5. **AltiRig:** the first thrust job is now a 5215-class motor with a 22 x 7 in propeller at 0.736 kg/m3.
6. **Kitewright Lift:** also supplies its own Core power leads under Core 33B; the lead set (8 AWG, four AS150 halves, labels) should match Range's BOM line 33.

### Recommended next step

- Re-render the hero, exploded and detail photoreal views on the Mac from the new scenes, then run the cards and the release gate. The design is ready for TRL 4 parts purchase and AltiRig thrust tests of the 5215-class motor with a 22 in propeller; that is a recommendation only, not started.

## 2026-10-04: Amish's round-3 decisions carried out

Amish Chadha (owner) on 2026-10-04: "For round 3, I agree with all your proposed recommendations". For Kitewright Range that is its share of the Kitewright family reconciliation, item 10A: AS150 plugs everywhere (Range's packs change from XT90), one mounting envelope for the Core shared with Lift with the Core's drawing as the reference, and Range recomputed with the 0.99 kg Core. Core, Lift, ColdCell, AvalancheScout and LakeWatch were brought to the same table in the same session. Recorded in `docs/decisions/0004-family-reconciliation.md` (KWR-DDR-004) and the register (`docs/06-design-decisions.md` v0.3). Nothing was committed or pushed.

### Changes made

- **Model** (`cad/src/model.py`, new `cad/src/core_envelope.py`): the Kitewright Core hung under the floor at the centre of gravity (four M4 on 220 x 130 mm into a new 6 mm birch Core deck doubler, lid up through a 200 x 112 mm floor opening, rail pointing aft); fuselage 156 mm wide (was 140); rear bulkhead at 645 mm (was 585); front pack in the nose bay and rear pack on the doubler behind the lid; payload envelope 140 x 88 x 100 mm on a payload shoe inside the Core's neck. All 75 solids in 49 parts pass the checks (no overlaps, nothing floating, discs 77 mm below the wing-top plane, transport lengths). STEP and STL regenerated.
- **BOM** (`bom/bom.csv`): lines 1, 2, 26, 27, 28 and 29 changed, each with a price basis (wider sheets and doubler USD 6, antenna extension leads USD 15; AS150 at the XT90's price class).
- **Calculations** (`docs/04-calcs/sizing.py`, `01-sizing.md` v0.4, `results.csv`): Core 0.99 kg with its rail and pins, the Core's underside drag, the wider fuselage; every section re-run.
- Documents: `docs/03-requirements.md` v0.5 (status only; no requirement restated), `docs/05-build-plan.md` v0.3, `docs/02-concept.md` v0.5, `README.md`.

### New result per requirement (KWR-CAL-001 v0.4)

| Requirement | Before (v0.3) | Now | Status |
| --- | --- | --- | --- |
| R1 hover margin (at least 30 %) | 52.0 % | 48.3 % | Met on paper |
| R2 endurance (at least 45 min) | 32.9 min | 30.6 min | Not met (accepted) |
| R3 range (at least 40 km) | 44.3 km | 41.5 km | Met on paper, 4 % margin |
| R4 balance | 27.5 % MAC | 28.3 % MAC, payload on the CG | Met by design |
| R7 take-off mass (8 kg or less) | 11.07 kg | 11.35 kg | Not met (accepted) |
| R9 discs below wing-top plane | 77 mm | 77 mm | Met by design |
| R10 cost | USD 4,293 | Value-engineering target: USD 5,000. Estimated cost of the constructable design: USD 4,314 (USD 686 under the target) | Met on paper |

The brief expected about 32.9 min after reconciliation. The 0.99 kg Core's mass alone would cost only about 0.3 to 0.5 min, but carrying the Core to its drawing also costs the doubler, a wider fuselage and the Core's drag under the floor: 30.6 min in all. LakeWatch's R5 is restated on this 30.6 min.

### Kitewright interface table

The same table stands in the review notes of Kitewright Core, Kitewright Lift, Kitewright Range, ColdCell, AvalancheScout and LakeWatch (Amish's decision 10A, 2026-10-04). The Core's drawings are the reference for the mounting envelope.

| Interface | Family figure | Source |
| --- | --- | --- |
| Power connector | AS150 on every pack lead and on each frame's power harness (two pack inputs, two frame outputs, opposite genders); no XT60 or XT90 on the bus | Decision 10A; KWC-DDR-001, D3 |
| Core mounting envelope and hole pattern | Core plate 240 x 150 x 2 mm hung under the frame's lower deck on four 12 mm OD x 8 mm corner spacers; four M4 holes on a 220 x 130 mm pattern; a 200 x 112 mm opening in the deck for the lid; lid 168 x 92 mm, its top 55 mm above the deck's underside (GNSS mast boss 69 mm); where a frame has no 240 mm clear above the lid, the antennas and GNSS receiver go to frame positions on extension cables; rail, pin blocks and pin knobs to 47 mm below the plate top; payload shoe 184 x 128 x 5 mm, payload neck 88 mm wide from the shoe to 30 mm below the rail lips | KWC-DWG-001 Rev P2, KWC-DWG-106 |
| Bus voltage | 18 to 60 V at the Core's pack inputs. Lift: 14S lithium-ion, 42.0 to 58.8 V (50.4 V nominal). Range: 6S lithium-ion, 18.0 to 25.2 V (21.6 V nominal) | KWC-DDR-001, D3 |
| Pack size and mass | Lift: two ColdCell 14S3P lithium-ion packs, 410 x 94 x 94 mm, 4.46 kg and 680 Wh each (CCL-DWG-002). Range: two 6S3P lithium-ion packs of 5.0 Ah cells, 138 x 75 x 82 mm, 1.40 kg and 324 Wh each (Range's figure; ColdCell has not yet drawn this pack) | Decision 8A; CCL-CAL-001 K; KWR-CAL-001 |
| Core mass | 0.99 kg: avionics, radios, GNSS, rail and locking pins; packs, payload shoe and the frame's harness excluded | Core R9; KWC-DDR-003 |

### Pictures changed

General arrangement KWR-DWG-001 Rev P4; making sketches KWR-DWG-101 (fuselage box) and 102 (hatch) Rev P2, the others redrawn unchanged; build plan overview, all eight joints (joint-08 now the battery bays and the Core under the floor) and all sixteen steps (step 4 the doubler, step 5 the Core under the floor); concept media (hero, cutaway, exploded, flow, blueprint, `model.glb`). Looked at: joint-08. `cad/src/product_model.py` takes the Core, its rail and the doubler from `model.py`; render scenes exported to `/home/claude/renders/kitewright-range` (hero, exploded, detail). The photoreal renders, captions and cards in `media/` predate this change and need a re-run on Amish's Mac.

### Open decisions

None. The lower endurance and range keep their status (R2 not met and accepted, R3 met on paper), so nothing new needs Amish.

### Safety

- The Core's pin knobs hang 140 mm and the payload 80 mm above the ground on the landing feet: land only on clear ground, and walk the aircraft round before arming.
- The Core power leads are soldered with every pack disconnected; polarity checked at each AS150 plug with a meter before the first pack goes on.
- Packs: unchanged rules; charge between 0 and 45 °C pack temperature in a fire-resistant box.

### Cross-repo actions

- **ColdCell:** the Range pack (6S3P of 5.0 Ah 21700 cells, 138 x 75 x 82 mm, 1.40 kg, 324 Wh, AS150) is still Range's figure; ColdCell has not drawn it. It is listed so in the interface table.
- **LakeWatch:** plans its surveys on 30.6 min (its R5, restated in its own repository the same day).

### Recommended next step

Re-render the hero, exploded and detail photoreal views on the Mac from the new scenes. The design is ready for TRL 4 parts purchase and AltiRig thrust tests; a recommendation only, not started.

## 2026-10-04: photoreal renders redone after the round-2 and round-3 decisions

Views: hero, exploded, detail; cards regenerated; image_qc passes and `render.py --check` has no FAIL.

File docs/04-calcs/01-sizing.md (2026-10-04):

---
doc_id: KWR-CAL-001
title: Kitewright Range sizing calculations
project: Kitewright Range
doc_type: Calculation
version: "0.4"
status: Draft
date: '2026-10-04'
author: Amish Chadha
license: CERN-OHL-S-2.0
revisions:
- version: "0.1"
  date: '2026-10-03'
  author: Amish Chadha
  change: First issue for TRL 3 (mass and balance, aerodynamics, hover at 5,000 m, energy and endurance, structure, design-around geometry, transport, cost)
- version: "0.2"
  date: '2026-10-03'
  author: Amish Chadha
  change: Design for construction (KWR-DDR-002) applied; masses from the constructable model; options for the requirements not met
- version: "0.3"
  date: '2026-10-03'
  author: Amish Chadha
  change: 'Amish''s 2026-10-03 decisions applied (KWR-DDR-003; Amish: "i agree with all the 46 recommendations you provided. please proceed."): 22 in propellers on 5215-class motors, booms 50 mm longer and 20 mm further out, 5.0 Ah cells in the same two packs, airframe kept, Kitewright Core power leads now supplied by Range'
- version: "0.4"
  date: '2026-10-04'
  author: Amish Chadha
  change: 'Amish''s round-3 decision 10A applied (KWR-DDR-004; Amish: "For round 3, I agree with all your proposed recommendations"): the Kitewright Core to the family envelope under the fuselage floor at the centre of gravity (0.99 kg), fuselage 156 mm wide, Core deck doubler, packs moved, AS150 on the packs; every section re-run'
---

# Kitewright Range sizing calculations

On paper, Kitewright Range takes off and lands vertically at 5,000 m with a 48.3 % thrust margin and flies 30.6 min and 41.5 km on the wing with a 1 kg payload and a 20 % reserve, at a take-off mass of 11.35 kg. This version carries Amish's round-3 decision 10A of 2026-10-04 (KWR-DDR-004: "For round 3, I agree with all your proposed recommendations"): Range is recomputed with the 0.99 kg Kitewright Core, hung under the fuselage floor at the centre of gravity to the family mounting envelope (the Core's drawing is the reference), with AS150 plugs on the packs. The 2026-10-03 decisions (KWR-DDR-003) stand. Eight requirements are met on paper or by design; endurance (R2, 30.6 min against 45 min) and take-off mass (R7, 11.35 kg against 8 kg) are not met, as Amish accepted for the first prototype. The estimated cost is USD 4,314 against the USD 5,000 value-engineering target (USD 686 under).

## Scope and method

The script `docs/04-calcs/sizing.py` reads the constructable geometry from `cad/src/model.py`, takes the mass of every made part from its modelled volume and surface area, adds the bought parts, and works out balance, drag, cruise and hover power, energy per flight, structural margins and cost. It writes `docs/04-calcs/results.csv`. All figures are first-order estimates for TRL 3; motor and propeller data must be measured in AltiRig at 5,000 m air density before any flight.

## Assumptions

Table 1. Assumptions

| Quantity | Value | Basis |
| --- | --- | --- |
| Air density at 5,000 m | 0.736 kg/m3 | ISA (R1 uses 0.74 kg/m3) |
| Wing | NACA 2412, 0.704 m2, span 2.50 m, aspect ratio 8.9 | Model |
| Maximum lift coefficient | 1.30 | Plain ailerons, Reynolds number about 3 x 10^5 |
| Oswald factor | 0.75 | Booms and pylons disturb the span loading |
| Skin friction, form factors | Cf 0.006; wing 1.25, tail 1.20; interference 1.15 | Hand-book build-up |
| Lift thrust per motor at sea level | 68.7 N (7.0 kgf) | Maker class figure for a 5215-class motor with a 22 x 7 in propeller on 6S (KWR-DDR-003); to be measured |
| Thrust at altitude | Sea-level thrust x density ratio (0.601) | Conservative: ignores the higher rpm a lighter load gives |
| Hover figure of merit, drive efficiency | 0.65, 0.82 | Typical for 20 to 22 in carbon propellers and open ESCs |
| Cruise propeller and drive efficiency | 0.65 and 0.85 (0.55 combined) | 14 x 10 in folding propeller at 22 m/s |
| ColdCell packs | Two packs, 6S3P Li-ion high-rate 21700 cells of 5.0 Ah, 324.0 Wh and 1.40 kg each, AS150 leads | Range's figure in the Kitewright interface table (ColdCell has not yet drawn this pack); 5.0 Ah cells per KWR-DDR-003 |
| Usable energy | 90 % depth of discharge x 95 % for cold, packs warmed before take-off | ColdCell heater keeps the cells above 15 °C |
| Reserve | 20 % of usable energy kept for landing | R2 |
| Kitewright Core | 0.99 kg with its rail and pins, at the centre of gravity under the floor; its GNSS receiver on the hatch mast (0.03 kg) and antennas on extension leads (0.03 kg) | Core R9; the Kitewright interface table of 2026-10-04 (decision 10A) |
| Kitewright Core power leads | 0.124 kg at the rear of the Core | Core decision 33B moves them to the frame; Core BOM line 21 |
| Systems power | 38 W: avionics 15, payload 10, pack heaters in flight 10, servos 3 | Estimate |
| Vertical phases | 125 s at hover power plus 20 % for transitions | Take-off, two transitions, landing |
| Climb | 400 m at 2.5 m/s on the wing | Launch site to survey height |
| Limit load factor | 2.5 g | Gusts and turns in valley wind |
| Carbon tube allowable bending stress | 600 MPa | Pultruded and roll-wrapped tube |
| Printed parts | ASA, 1,070 kg/m3, walls and infill per part | `sizing.py` |

## A. Mass and balance (R4, R7)

Take-off mass is 11.35 kg, of which the payload is 1.00 kg and the two ColdCell packs 2.80 kg. The largest made parts are the fuselage box (0.83 kg), the two wing panels with spars and ailerons (0.57 kg each) and the two boom pylons (0.14 kg each). The four 5215-class lift motors weigh 1.14 kg and the lift system with propellers, mounts and ESCs 1.68 kg. The Kitewright Core weighs 0.99 kg with its rail and pins; the Core power leads add 0.12 kg.

Against v0.3 (11.07 kg) the reconciliation adds 0.28 kg: the Core, GNSS and payload mount 0.15 kg (0.99 kg of Core, 0.03 kg of hatch mast and 0.03 kg of antenna leads against the 0.70, 0.08 and 0.12 kg assumed before), the 6 mm birch Core deck doubler 0.09 kg, and the fuselage 16 mm wider 0.04 kg.

The Core hangs under the floor at the centre of gravity, so the payload on its shoe sits there too, and fitting or removing the 1 kg payload does not move the centre of gravity (R4). To balance the Core's move from the front bay, the front pack now sits in the nose bay (60 to 198 mm behind the firewall) and the rear pack on the doubler behind the Core's lid (506 to 644 mm), with the rear bulkhead moved from 585 to 645 mm. The centre of gravity is 415 mm behind the firewall, at 28.3 % of the 281 mm mean chord, 1 mm behind the target.

## B. Aerodynamics and cruise (R2, R3, R6)

Table 2. Drag areas at cruise

| Item | CdA (m2) |
| --- | --- |
| Lift motors, mounts and ESCs (stopped) | 0.0129 |
| Wing | 0.0109 |
| Fuselage and nose, 156 x 150 mm | 0.0082 |
| Payload, 88 x 100 mm | 0.0035 |
| Leg fairings and feet | 0.0034 |
| Kitewright Core underside: plate, rail and shoe edge (0.150 x 0.024 m) and two pin knobs | 0.0027 |
| Pylons | 0.0024 |
| Tail surfaces | 0.0023 |
| Booms, stopped propellers, mast, pitot and tail boom | 0.0051 |
| Total with 15 % interference | 0.0591 |

The zero-lift drag coefficient is 0.083 (0.079 in v0.3): the Core hung under the floor and the wider fuselage add 0.0033 m2. Wing loading is 157 N/m2 and the stall speed at 5,000 m is 18.1 m/s. The lowest-power speed above 1.25 times stall is 22.6 m/s at a lift coefficient of 0.83 and a lift-to-drag ratio of 7.2. The air needs 353 W, which is 676 W from the packs with the propeller, drive and 38 W of systems.

Wind (R6): cruise at 22.6 m/s is well above a 14 m/s gust. In hover a 14 m/s side gust needs a tilt of about 9 degrees, inside the authority left by the hover margin.

## C. Hover at 5,000 m (R1)

The four 22 in rotors sweep 0.981 m2, a disc loading of 114 N/m2. The packs supply 1,835 W in hover (85 A at 21.6 V, 14.2 A per cell, inside the high-rate cells' rating). Maximum thrust at altitude is 4 x 68.7 N x 0.601 = 165.1 N against a weight of 111.3 N: a **48.3 % thrust margin**. At sea level the same rotors hover at 41 % of maximum thrust.

## D. Energy, endurance and range (R2, R3)

Table 3. Energy per flight at 5,000 m

| Stage | Wh |
| --- | --- |
| Two packs, nominal | 648 |
| Usable with packs warmed | 554 |
| Kept as 20 % reserve | 111 |
| Hover, transitions | 76 |
| Climb 400 m | 22 |
| Left for cruise | 344 |

At 676 W the cruise energy gives **30.6 min** on the wing and **41.5 km** of survey track at 22.6 m/s. Against v0.3 (32.9 min) the 0.99 kg Core's extra mass alone costs about 0.5 min, the doubler, wider fuselage and leads about 1.0 min, and the drag of the Core under the floor and the wider fuselage about 1.2 min. LakeWatch plans its surveys on this figure (its R5, restated on 2026-10-04).

## E. Structure

Table 4. Bending checks at limit load

| Item | Load case | Moment | Safety factor on 600 MPa |
| --- | --- | --- | --- |
| Wing spar 22 x 20 at the root | 2.5 g, lift centroid at 45 % of the panel | 73.9 N m | 2.7 |
| Joiner 20 x 16 inside the spars | Same | 73.9 N m | 3.8 |
| Lift boom 25 x 23 at the pylon edge | One 5215-class motor at sea-level full thrust (68.7 N) | 31.0 N m | 8.4 |
| Tail boom 20 x 17 | Stabiliser load of 15 % of weight at 2.5 g | 40.5 N m | 5.6 |
| Pylon bolts, two M5 per pylon | Both motors at full thrust plus one motor alone | 434 N | 9.9 on 4.3 kN proof |

All margins are above 2. The wing spar is the tightest and is checked again with a proof load at TRL 4.

## F. Geometry rules (R8, R9)

With the booms at 490 mm from the centre line and the motors 531 mm ahead of and behind the centre of gravity, the 22 in rotor discs sit 77 mm below the wing-top plane (the rule is at least 70 mm), the front discs clear the leading edge by 171 mm and the rear discs the trailing edge by 44 mm, the lift discs clear the cruise propeller disc by 33 mm (the model's rule is 20 mm), the fuselage side by 133 mm and the stabiliser by 110 mm. The Kitewright Core's pin knobs are 140 mm and the payload 80 mm above the ground on the landing feet. Motors are fixed and do not tilt, there is one wing, and the aircraft is not a tail-sitter. The longest part is a wing panel at 1,205 mm with its root fittings, then the lift boom at 1,142 mm; all fit 1.3 m cases. Tail volume coefficients are 0.53 (horizontal) and 0.025 (vertical).

## G. Cost (R10)

Value-engineering target: USD 5,000. Estimated cost of the constructable design: USD 4,314 (USD 686 under the target), including Range's share of the Kitewright Core (USD 900 and USD 60 for its rail), two ColdCell packs of 5.0 Ah cells (USD 700) and two transport cases (USD 360), excluding the payload. Decision 10A adds USD 21: the wider fuselage sheets USD 2, the doubler and T-nuts USD 4 and the antenna extension leads USD 15; the AS150 plugs cost the same class as the XT90s.

## H. Decisions taken and the options left

Amish decided the four options of KWR-CAL-001 v0.2 on 2026-10-03 ("i agree with all the 46 recommendations you provided. please proceed."): R1 option B (22 in propellers on 5215-class motors), R2 and R3 option A (5.0 Ah cells in the same packs), R7 option A (keep the airframe, weigh it at TRL 4). Table 5 gives the design as it now stands and the options that remain for R2 and R7 for a second prototype, worked out with the same script.

Table 5. Design as decided and the options left (changes from the design as it stands)

| Option | Take-off mass | Hover margin | Endurance | Range | Cost change |
| --- | --- | --- | --- | --- | --- |
| Design as decided (KWR-DDR-003, KWR-DDR-004) | 11.35 kg | 48.3 % | 30.6 min | 41.5 km | USD 0 |
| Two 6S4P packs of 5.0 Ah cells | 12.23 kg | 37.6 % | 38.4 min | 54.2 km | +USD 240 |
| Moulded carbon wing, tail and fuselage | 10.66 kg | 57.9 % | 34.2 min | 45.1 km | +USD 1,200 |
| Moulded airframe and two 6S4P packs | 11.54 kg | 45.9 % | 42.5 min | 58.2 km | +USD 1,440 |

With the reconciled Core no line meets R2 on paper any more; the last comes closest (42.5 min, USD 5,754 in all). It remains the second-prototype path once the first prototype's drag and mass are measured. Table 5 of v0.3 is superseded.

## L. Results against every requirement

Table 6. Results

| ID | Result | Status |
| --- | --- | --- |
| R1 | 48.3 % thrust margin at 0.736 kg/m3 and 11.35 kg, on maker-class thrust | Met on paper: 18 points above the line; to measure in AltiRig |
| R2 | 30.6 min on the wing at 5,000 m with 1 kg and 20 % reserve | **Not met** (accepted for the first prototype, KWR-DDR-003) |
| R3 | 41.5 km of survey track | Met on paper: 4 % above the line |
| R4 | 1 kg on the Core's payload shoe under the CG; CG 28.3 % of the mean chord with or without it | Met by design |
| R5 | All electronics and servos specified to -20 °C or tested cold; packs heated | Met on paper; to confirm when parts are bought |
| R6 | 22.4 m/s cruise against 14 m/s gusts; about 9 degrees of tilt to hold a side gust in hover | Met on paper |
| R7 | 11.35 kg take-off mass | **Not met** (airframe kept and weighed at TRL 4, KWR-DDR-003) |
| R8 | Longest part 1,205 mm; two cases about 9 kg and 12.5 kg | Met by design |
| R9 | Fixed motors, one wing, discs 77 mm below the wing-top plane | Met by design |
| R10 | USD 4,314; every part bought or made with hobby tools | Met on paper; USD 686 under the value-engineering target |

## Checks against the TRL 2 figures

The precis estimated a take-off mass near 8 kg and the problem statement assumed hover time near 47 % of sea level at 5,000 m. The constructable design is 3.4 kg heavier than that estimate: the ColdCell packs alone are 2.8 kg for 648 Wh, and the 22 in lift system with its mounts and ESCs is 1.7 kg. That is why R2 and R7 are missed together: more energy costs mass, and less mass costs energy.

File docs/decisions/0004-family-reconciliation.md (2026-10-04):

---
doc_id: KWR-DDR-004
title: Kitewright Range round-3 decision, Kitewright family reconciliation
project: Kitewright Range
doc_type: Design decision record
version: "0.1"
status: Draft
date: '2026-10-04'
author: Amish Chadha
license: CERN-OHL-S-2.0
revisions:
- version: "0.1"
  date: '2026-10-04'
  author: Amish Chadha
  change: Amish's round-3 decision 10A carried out for Range
---

# 0004: Kitewright family reconciliation (round 3)

- **Date:** 2026-10-04
- **Status:** accepted. Decided by Amish Chadha on 2026-10-04: "For round 3, I agree with all your proposed recommendations" (round 3, item 10A).

## Context

Range had assumed a 180 x 110 x 60 mm Core avionics box of 0.70 kg in its front bay, a separate 160 x 80 x 12 mm payload mount of 0.12 kg under the centre of gravity, a GNSS mast of 0.08 kg and XT90 leads on its packs. The Core, after its decision 33B, is a 240 x 150 mm plate with its own rail and pins that hangs under a frame's deck on a 220 x 130 mm M4 pattern, weighs 0.99 kg and takes AS150 plugs (KWR-CAL-001 v0.3 noted the gap and an estimate of 0.3 min less endurance from the mass alone).

## Decision

10A: AS150 plugs everywhere; one mounting envelope for the Core shared by Lift and Range, with the Core's drawing as the reference; Range recomputed with the 0.99 kg Core; the Kitewright interface table in each repository's review note.

## Carried out

| Item | Was | Now |
| --- | --- | --- |
| Kitewright Core | Avionics box in the front bay; separate payload mount plate under the CG | The Core hung under the floor at the CG to KWC-DWG-001 (`cad/src/core_envelope.py`, the same file as Lift's), its rail pointing aft so payloads slide in from the tail |
| Fuselage | 140 mm wide; rear bulkhead at 585 mm | 156 mm wide (150 mm inside, as the Core asks); floor cut with the 200 x 112 mm opening and four 4.3 mm holes; rear bulkhead at 645 mm |
| Core deck doubler (new) | None | 6 mm birch, 300 x 150 mm, with the opening, four holes and M4 T-nuts, on the floor |
| Packs | Either side of the joiner on the floor | Front pack in the nose bay (60 to 198 mm), rear pack on the doubler behind the lid (506 to 644 mm); the centre of gravity stays at 28.3 % of the mean chord |
| GNSS and antennas | GNSS mast on the hatch | The Core's GNSS receiver on the hatch mast and its three antennas on the hatch, on extension cables |
| Payload envelope | 150 x 90 x 100 mm under a mount plate | 140 x 88 x 100 mm under a 184 x 128 x 5 mm payload shoe, inside the Core's 88 mm neck and clear of its pigtail plug |
| Pack leads | XT90 | AS150 |

## Results (KWR-CAL-001 v0.4)

- Take-off mass 11.35 kg (0.28 kg more); hover margin 48.3 % (R1 met on paper); endurance 30.6 min (R2 not met, accepted); range 41.5 km (R3 met on paper, 4 % margin); centre of gravity 28.3 % of the mean chord (R4).
- Value-engineering target: USD 5,000. Estimated cost of the constructable design: USD 4,314 (USD 686 under the target).
- The endurance falls 2.4 min, not the 0.3 min the Core's mass alone would cost: the doubler, wider fuselage and leads cost about 1.0 min and the drag of the Core hung under the floor about 1.2 min. LakeWatch's R5 is restated on 30.6 min.

## Consequences

- No option in KWR-CAL-001 section H now meets R2 on paper; the moulded airframe with 6S4P packs comes closest (42.5 min).
- R3's margin is 4 %; a measured drag or thrust shortfall at TRL 4 could take it below 40 km.

> **Safety:** The Core's pin knobs hang 140 mm above the ground and the payload 80 mm; land only on the four feet on clear ground. The Core power leads are soldered with every pack disconnected and checked for polarity before the first pack goes on.

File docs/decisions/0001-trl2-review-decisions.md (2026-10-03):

---
doc_id: KWR-DDR-001
title: Kitewright Range TRL 2 review decisions
project: Kitewright Range
doc_type: Design decision record
version: "0.1"
status: Draft
date: '2026-10-03'
author: Amish Chadha
license: CERN-OHL-S-2.0
revisions:
- version: "0.1"
  date: '2026-10-03'
  author: Amish Chadha
  change: TRL 2 review decisions D1 to D10, decided under Amish's 2026-10-03 pre-approval
---

# 0001: TRL 2 review decisions

- **Date:** 2026-10-03
- **Status:** accepted under Amish's pre-approval. Amish, 2026-10-03: "start with the first 14 repos from the list of 29 projects. I pre-approve the batch runs along with any recommendations you come up with. I also accept any cost overruns or variations from the assumed scope cost." and, for this batch, "Proceed with the remaining 15 scaffolds".

## Context

The scaffold (KWR-PRB-001 v0.1) left five open questions: the reference firmware, the wing span and aspect ratio, one or two propeller sets, whether 1 kg of payload is enough for LakeWatch with its winch, and the first co-design partner. Populating the concept to TRL 2 needed further choices on layout, battery, materials and safety. Each was decided as recommended under the pre-approval above. Requirements that the design does not meet are not decided here; they are open decisions for Amish in `docs/06-design-decisions.md`.

## Options considered and decisions

Table 1. Decisions

| # | Question | Options considered | Decision | Reason |
| --- | --- | --- | --- | --- |
| D1 | Reference firmware | PX4; ArduPilot | PX4 quadplane (VTOL standard) with published parameters; an ArduPilot QuadPlane set may follow | Kitewright Core targets upstream PX4 with no source changes |
| D2 | Wing span and aspect ratio | 2.2 m one piece; 2.5 m in two panels; 3.0 m in three panels | 2.50 m in two 1.18 m panels on a carbon joiner, NACA 2412, root chord 310 mm, tip 250 mm, aspect ratio 8.9 | Largest span whose panels fit a 1.3 m case (R8) with one joint |
| D3 | One or two propeller sets | One set; a low-altitude and a high-altitude set | One set of 20 x 6.5 in propellers for all altitude bands | At sea level they hover at 46 % of maximum thrust, which is efficient enough; one set avoids a wrong-set crash |
| D4 | LakeWatch sampling winch | On Range; on Lift only | 1 kg payload on the Core mount for Range; the sampling winch belongs on Kitewright Lift | A winch needs a hover over one point, which is Lift's job |
| D5 | Layout of the cruise motor and tail | Pusher at the tail with a twin-boom tail; tractor at the nose with a tail boom | Tractor cruise motor with a folding propeller at the nose; conventional tail on a carbon tail boom; lift booms on pylons below the wing | Keeps the lift booms short enough for the cases and the rear rotor wash off the tail |
| D6 | Battery | One or two ColdCell packs; Li-ion or LiPo | Two ColdCell 6S3P Li-ion 21700 packs in parallel, one either side of the wing joiner | Li-ion gives the most energy per kilogram for cruise; two packs share hover current |
| D7 | Materials | Moulded composite; foam, glass, lite-ply and printed parts | Hot-wire cut foam with glass skins, lite-ply fuselage, carbon tubes, printed ASA fittings | Buildable with hobby tools (R10) and repairable in the field |
| D8 | First co-design partner and region | State disaster authority; university glaciology group; mountain NGO | First candidate to approach: the Sikkim State Disaster Management Authority, for lake sites in Sikkim, India; second candidate: a university glaciology group already flying Himalayan lake surveys. Not agreed with either | Sikkim has the high-risk lakes and the 2023 South Lhonak outburst; the authority holds the sites and permissions |
| D9 | Safety approach for powered tests (conservative) | Free hover from the first power-up; staged tests | Staged: motors run with propellers off first; first hovers tied down to ground anchors inside a 15 m keep-out zone; a removable arming plug and a lockable arming switch; no propeller fitted on the bench; packs charged only between 0 and 45 °C pack temperature in a fire-resistant box. Relax the tie-down only after 10 logged tied hovers with no fault, and the keep-out only with the partner's site rules | Large propellers and lithium packs are the main hazards (see safety section) |
| D10 | Failsafes (conservative) | Return and land; land in place | Loss of link or low battery: return to launch on the wing, then land vertically; land in place if the battery reaches the reserve; geofence around the survey area | Remote terrain makes a controlled return safer than an uncontrolled landing |

## Consequences

- The constructable design (KWR-DDR-002) and the calculations (KWR-CAL-001) follow D1 to D10.
- D3 is to be confirmed by AltiRig thrust data at 5,000 m density; D6 depends on the ColdCell format, listed as a cross-repo assumption in `docs/REVIEW.md`.
- D8 records candidates only; no partner has been contacted.

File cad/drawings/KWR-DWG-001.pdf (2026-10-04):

CONCEPT, NOT FOR FABRICATION | Kitewright Range · github.com/BoujeeEnjinia1701/kitewright-range

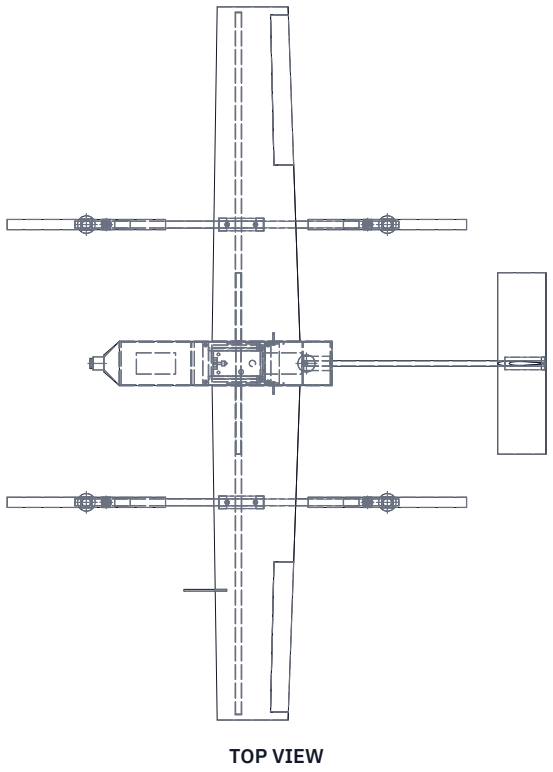
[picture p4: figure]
TOP VIEW

FRONT VIEW
Scale 1:25; looking at the front (along +Y)

Scale 1:25; looking down (along -Z)

RIGHT VIEW
Scale 1:25; looking at the right side (along -X)

1901

2516 634

ISOMETRIC VIEW
Not to scale; seen from the front right and above

MAIN DIMENSIONS AND INTERFACES (MM)
Span 2,516: two wing panels 1,180 on a 20 carbon joiner
Wing NACA 2412, chord 310 root to 250 tip; spar 22 OD at 30 % chord Fuselage 750 x 156 x 150; nose to tail 1,615, 1,901 over the lift propellers
Lift booms 25 OD x 1,142 at y = +/-490, on pylons below the wing
Lift motors 1,062 apart along each boom, centred on the CG at x = 414
Lift propellers 22 in (559) on 5215-class motors; discs 77 below the wing-top plane
Cruise motor at the nose, 14 in folding propeller; 33 gap to the lift discs
Tail on a 20 carbon boom: stabiliser 640 x 170, fin 300 high
Kitewright Core under the floor at the CG: M4 on 220 x 130, opening 200 x 112; payload shoe 80 clear of the ground under 1 kg Four landing legs, stance 980 x 922
Longest part for transport: wing panel 1,205
Third-angle; front view from -Y (left side); X aft from the firewall, Z up from the ground
REV | DESCRIPTION | DATE | BY
P1 | Preliminary GA for TRL 3 (KWR-CAL-001) | 2026-10-03 | AC
P2 | KWR-DDR-002: design for construction | 2026-10-03 | AC
P3 | KWR-DDR-003: 22 in propellers, 5215-class motors, longer booms | 2026-10-03 | AC
P4 | KWR-DDR-004: Kitewright Core envelope, 156 wide, AS150 | 2026-10-04 | AC
KITEWRIGHT RANGE | github.com/BoujeeEnjinia1701/kitewright-range

## All-electric quadplane survey frame: general arrangement

DRAWING NO.
KWR-DWG-001

REV
P4

SHEET
1 of 1

SIZE

## ANSI B

SCALE
1:25

UNITS
mm
PROJECTION | DATE
2026-10-04

DRAWN
Amish Chadha

MATERIAL / NOTES
Foam and glass wing and tail, lite-ply fuselage, carbon tubes, printed ASA fittings; bought parts per bom/bom.csv. PRELIMINARY, NOT FOR FABRICATION
Licensed CERN-OHL-S-2.0 · Design Molecule Lab · designmolecule.com | Generated from cad/src; do not edit by hand

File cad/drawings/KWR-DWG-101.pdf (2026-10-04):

BUILD PLAN SKETCH, PLAN NOT YET BUILT Kitewright Range · github.com/BoujeeEnjinia1701/kitewright-range

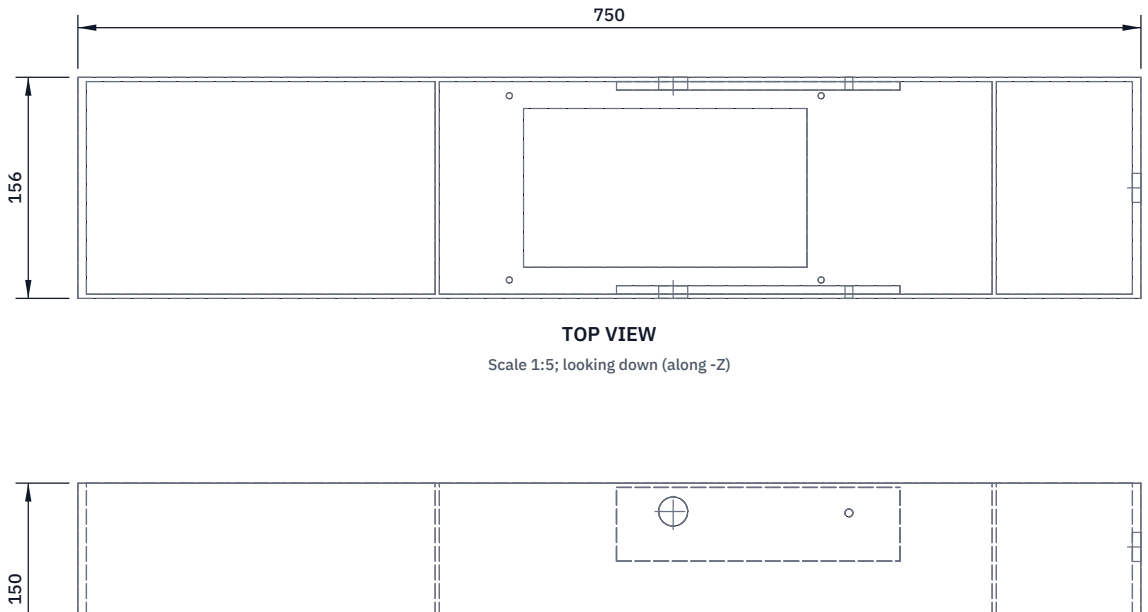
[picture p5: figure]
TOP VIEW; Scale 1:5; looking down (along -Z)

FRONT VIEW
Scale 1:5; looking at the front (along +Y)

RIGHT VIEW
Scale 1:5; looking at the right side (along -X)

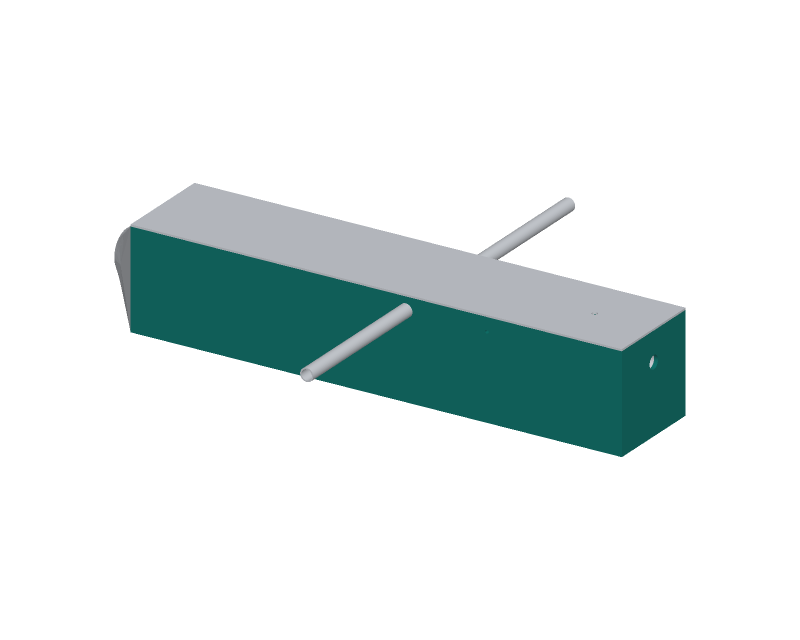
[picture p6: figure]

WHERE IT GOES
This part in colour, its neighbours in grey

HOW TO MAKE IT AND HOW IT FITS
Box 750 long, 156 wide, 150 high, open on top for the hatch.
Cut two sides and the floor from 3 mm lite-ply; firewall and rear wall from 6 mm birch ply. Two 3 mm bulkheads 252 and 645 back from the firewall face.
6 mm doublers inside each side, 200 x 52, top edge 3 below the rim.
Drill the joiner hole 20.5 through side and doubler, centre 420 back and 20 down from the rim. Drill the wing bolt hole 5.5, centre 544 back and 21 down; same on both sides.
Drill the rear wall 20.5 for the tail boom, 45 down from the rim, on the centre line.
Glue on a flat board with a square; check both joiner holes line up with a straight 20 mm rod.
Floor: cut the Kitewright Core's 200 x 112 lid opening centred 414 back, and four 4.3 holes on a 220 x 130 pattern round it. Bond the 6 mm birch Core deck doubler (300 x 150, same opening and holes, M4 T-nuts) on the floor inside.
Glass the outside with 80 g/m2 cloth; keep the floor flat under the Core's four spacers.
REV | DESCRIPTION | DATE | BY
P1 | Making sketch for the prototype build plan | 2026-10-03 | AC
P2 | KWR-DDR-004: 156 wide, Core opening and doubler, bulkhead 645 | 2026-10-04 | AC
KITEWRIGHT RANGE | github.com/BoujeeEnjinia1701/kitewright-range

## Kitewright Range: fuselage box making sketch

DRAWING NO.
KWR-DWG-101

REV
P2

SHEET
1 of 1

SIZE

## ANSI B

SCALE
1:5

UNITS
mm
PROJECTION | DATE
2026-10-03

DRAWN
Amish Chadha

MATERIAL / NOTES
3 mm poplar lite-ply sides, floor and bulkheads; 6 mm birch ply firewall, rear wall and doublers; glass cloth outside
Licensed CERN-OHL-S-2.0 · Design Molecule Lab · designmolecule.com | Generated from cad/src; do not edit by hand

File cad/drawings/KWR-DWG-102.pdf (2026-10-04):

BUILD PLAN SKETCH, PLAN NOT YET BUILT Kitewright Range · github.com/BoujeeEnjinia1701/kitewright-range

FRONT VIEW
Scale 1:5; looking at the front (along +Y)

TOP VIEW
Scale 1:5; looking down (along -Z)

RIGHT VIEW
Scale 1:5; looking at the right side (along -X)

750

156 3

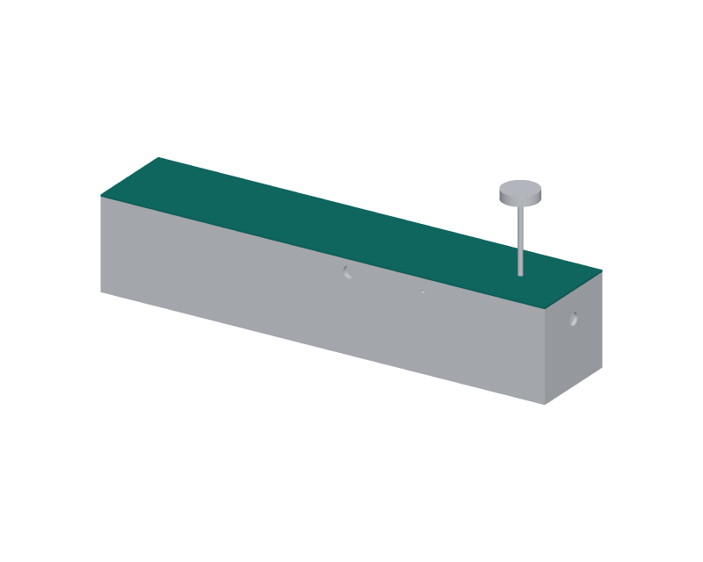
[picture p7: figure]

WHERE IT GOES
This part in colour, its neighbours in grey

HOW TO MAKE IT AND HOW IT FITS
Plate 750 x 156 x 3; sits on the side walls and bulkheads.
Glue a 20 mm tongue under the front edge that slides under a lip on the firewall.
One M4 nylon thumb screw at the back into a captive nut on the rear wall.
8.5 mm hole for the GNSS mast, 660 back from the front edge, on the centre line; the Core's GNSS receiver sits on top. Three 6.5 mm holes beside the mast for the Core's antennas on SMA extension leads.
Cut a slot for the lockable arming switch next to the mast (see the harness plan).
REV | DESCRIPTION | DATE | BY
P1 | Making sketch for the prototype build plan | 2026-10-03 | AC
P2 | KWR-DDR-004: 156 wide, antenna holes | 2026-10-04 | AC
KITEWRIGHT RANGE | github.com/BoujeeEnjinia1701/kitewright-range

## Kitewright Range: hatch making sketch

DRAWING NO.
KWR-DWG-102

REV
P2

SHEET
1 of 1

SIZE

## ANSI B

SCALE
1:5

UNITS
mm
PROJECTION | DATE
2026-10-03

DRAWN
Amish Chadha

MATERIAL / NOTES
3 mm poplar lite-ply
Licensed CERN-OHL-S-2.0 · Design Molecule Lab · designmolecule.com | Generated from cad/src; do not edit by hand

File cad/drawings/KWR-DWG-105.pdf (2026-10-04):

BUILD PLAN SKETCH, PLAN NOT YET BUILT Kitewright Range · github.com/BoujeeEnjinia1701/kitewright-range

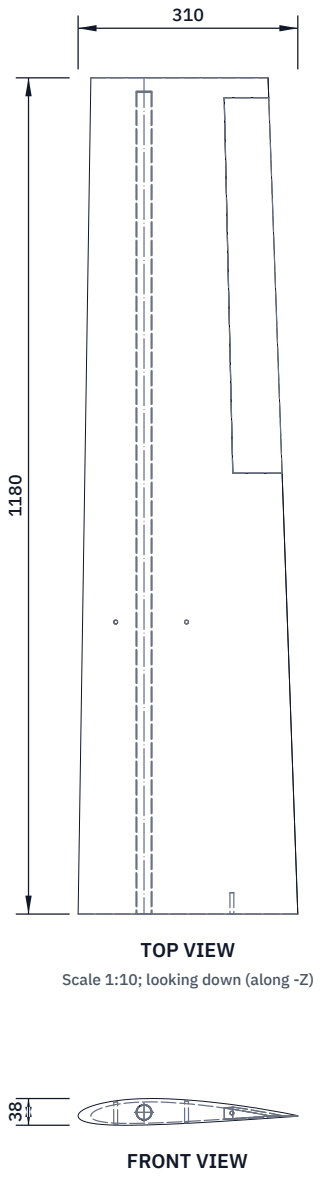
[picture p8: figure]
FRONT VIEW; TOP VIEW; Scale 1:10; looking down (along -Z)

Scale 1:10; looking at the front (along +Y)

RIGHT VIEW
Scale 1:10; looking at the right side (along -X)

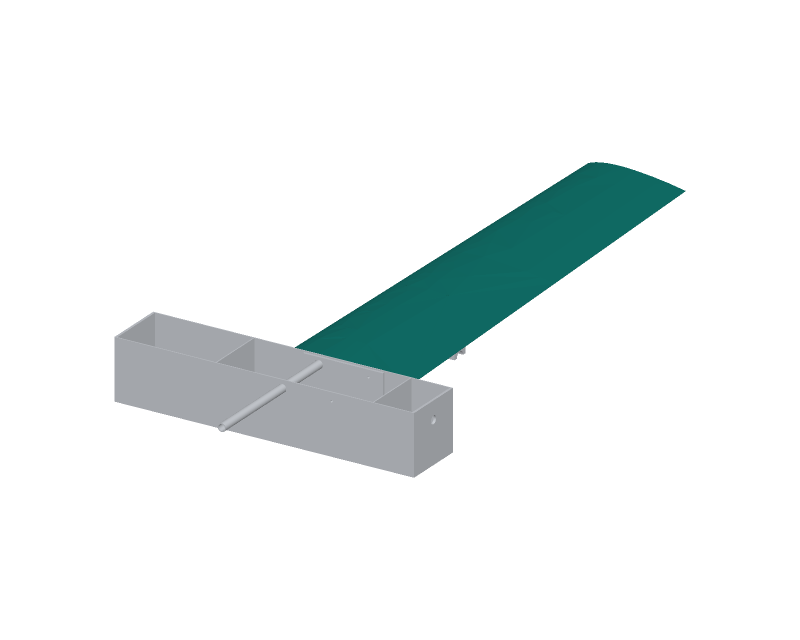
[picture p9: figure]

WHERE IT GOES
This part in colour, its neighbours in grey

HOW TO MAKE IT AND HOW IT FITS
Hot-wire cut NACA 2412 cores: root chord 310, tip chord 250, panel 1,180 long.
Keep the 30 % chord line straight: it is the spar line, square to the root rib.
Rout a 22 channel on the spar line and bond in the carbon spar, 1,160 long, flush with the root. Set two 3 mm ply hardpoints in the lower skin over the boom pylon, 490 out from the centre line. Lay a 10 mm conduit from the pylon to the root for the boom wires; servo bay behind the spar. Glass both sides; glue the 3 mm ply root rib with the 20 joiner hole and an M5 insert at 70 % chord. Cut the aileron free at 75 % chord from 700 to 1230 out; hinge on tape.
Make the left panel as a mirror image; the left panel also takes the pitot tube.
REV | DESCRIPTION | DATE | BY
P1 | Making sketch for the prototype build plan | 2026-10-03 | AC
KITEWRIGHT RANGE | github.com/BoujeeEnjinia1701/kitewright-range

## Kitewright Range: wing panel with aileron (make a left and a right) making sketch

DRAWING NO.
KWR-DWG-105

REV
P1

SHEET
1 of 1

SIZE

## ANSI B

SCALE
1:10

UNITS
mm
PROJECTION | DATE
2026-10-03

DRAWN
Amish Chadha

MATERIAL / NOTES
XPS foam 30 kg/m3, carbon spar tube 22 x 20, 80 g/m2 glass both sides, 3 mm ply root rib
Licensed CERN-OHL-S-2.0 · Design Molecule Lab · designmolecule.com | Generated from cad/src; do not edit by hand

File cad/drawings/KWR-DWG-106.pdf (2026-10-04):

BUILD PLAN SKETCH, PLAN NOT YET BUILT Kitewright Range · github.com/BoujeeEnjinia1701/kitewright-range

FRONT VIEW
Scale 1:2; looking at the front (along +Y)

TOP VIEW
Scale 1:2; looking down (along -Z)

RIGHT VIEW
Scale 1:2; looking at the right side (along -X)

160

44 107

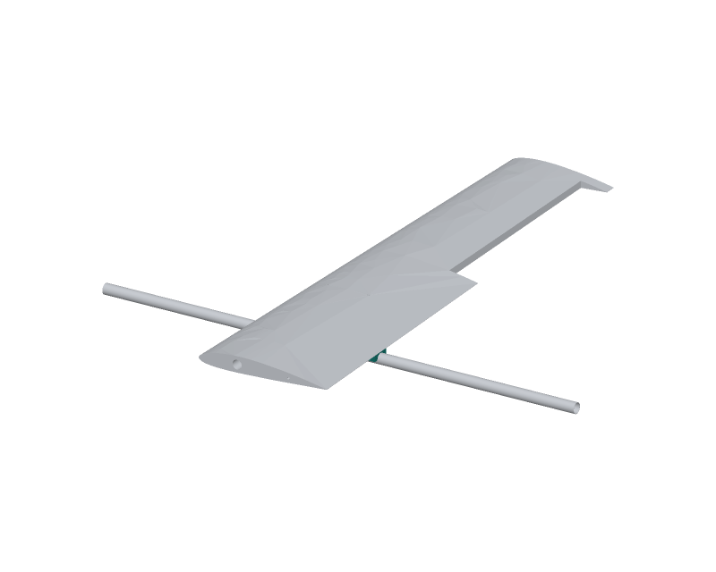
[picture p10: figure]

WHERE IT GOES
This part in colour, its neighbours in grey

HOW TO MAKE IT AND HOW IT FITS
Block 160 long, 44 wide; top shaped to the wing lower skin at 490 out.
Saddle on the bottom fits the 25 boom; the boom centre is 115 below the wing chord line. Two 5.5 holes on the centre line, 30 and 130 from the front, with M5 nut pockets.
Four M4 heat-set inserts in the underside for the clamp caps, 17 either side of the centre line. Print standing on its side; bond to the wing hardpoint with thickened epoxy, then fit the bolts. The pylon puts the rotor discs 77 below the wing-top plane: do not shorten it.
REV | DESCRIPTION | DATE | BY
P1 | Making sketch for the prototype build plan | 2026-10-03 | AC
KITEWRIGHT RANGE | github.com/BoujeeEnjinia1701/kitewright-range

## Kitewright Range: boom pylon (make 2) making sketch

DRAWING NO.
KWR-DWG-106

REV
P1

SHEET
1 of 1

SIZE

## ANSI B

SCALE
1:2

UNITS
mm
PROJECTION | DATE
2026-10-03

DRAWN
Amish Chadha

MATERIAL / NOTES
Printed ASA, 1.2 mm walls, 10 % gyroid infill
Licensed CERN-OHL-S-2.0 · Design Molecule Lab · designmolecule.com | Generated from cad/src; do not edit by hand

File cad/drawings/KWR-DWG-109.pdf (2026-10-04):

BUILD PLAN SKETCH, PLAN NOT YET BUILT Kitewright Range · github.com/BoujeeEnjinia1701/kitewright-range

FRONT VIEW
Scale 1:2; looking at the front (along +Y)

TOP VIEW
Scale 1:2; looking down (along -Z)

RIGHT VIEW
Scale 1:2; looking at the right side (along -X)

36

36 222

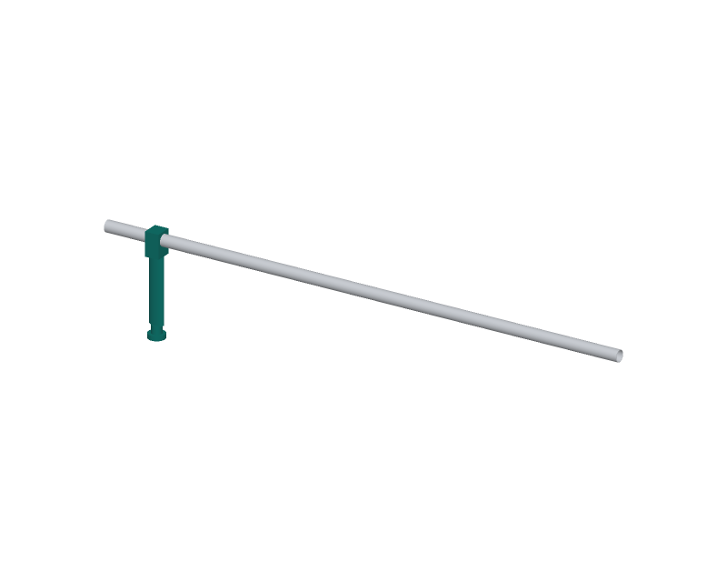
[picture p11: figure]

WHERE IT GOES
This part in colour, its neighbours in grey

HOW TO MAKE IT AND HOW IT FITS
Rod 12 mm, 182 long; clamp grips the boom 70 inboard of each motor.
Clamp: 30 long, 36 wide, split under the boom; two M3 bolts close it; 12 bore 20 deep for the rod. Fairing: elliptical 32 x 16, printed hollow, slides over the rod with its long axis fore and aft.
Foot: 36 round, 10 thick, with a 20 deep socket for the rod; print in TPU.
Glue the rod into the clamp and foot with epoxy; all four feet must touch a flat floor.
REV | DESCRIPTION | DATE | BY
P1 | Making sketch for the prototype build plan | 2026-10-03 | AC
KITEWRIGHT RANGE | github.com/BoujeeEnjinia1701/kitewright-range

## Kitewright Range: landing leg (make 4) making sketch

DRAWING NO.
KWR-DWG-109

REV
P1

SHEET
1 of 1

SIZE

## ANSI B

SCALE
1:2

UNITS
mm
PROJECTION | DATE
2026-10-03

DRAWN
Amish Chadha

MATERIAL / NOTES
Carbon rod 12 mm, printed ASA clamp and fairing, printed TPU foot
Licensed CERN-OHL-S-2.0 · Design Molecule Lab · designmolecule.com | Generated from cad/src; do not edit by hand

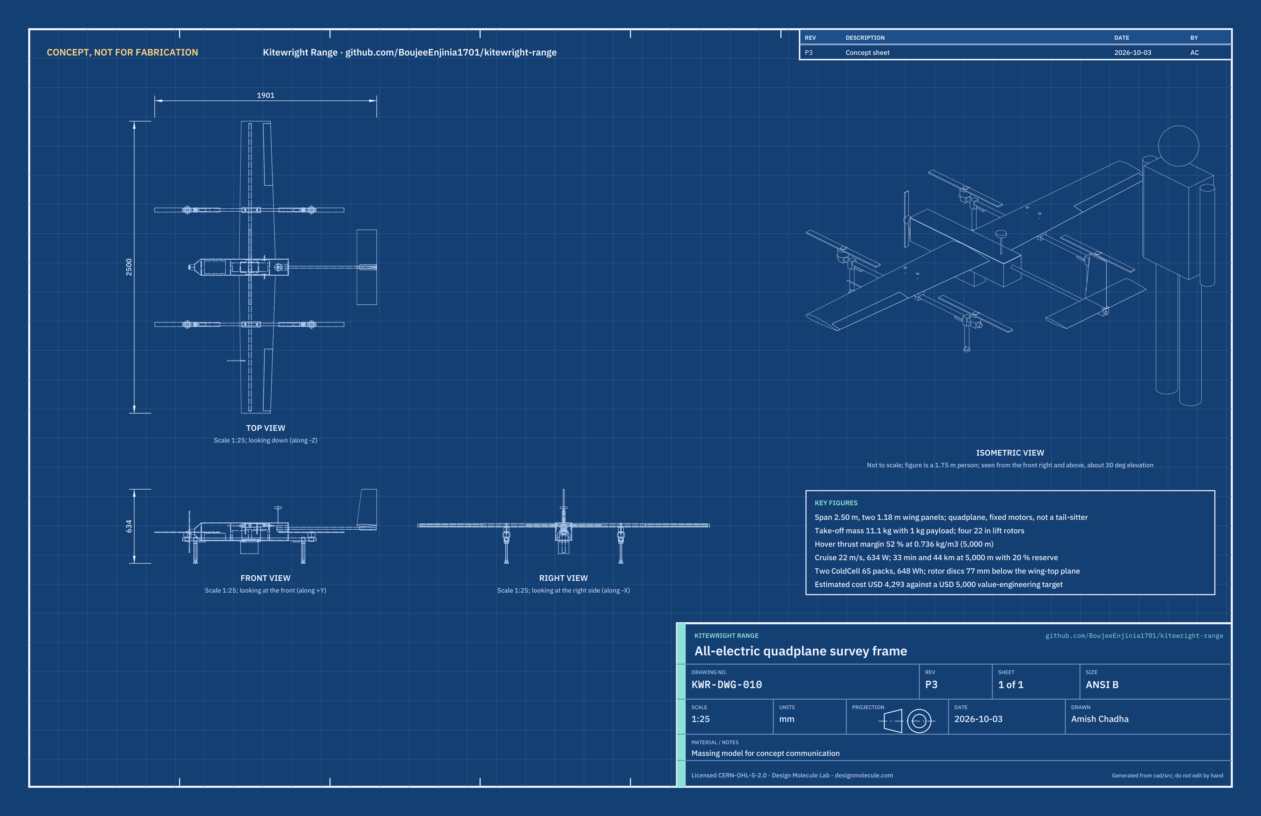
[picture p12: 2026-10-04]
media/concept-blueprint.png

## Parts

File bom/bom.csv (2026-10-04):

item | qty | spec | supplier | unit_cost_usd | make_buy | notes
1 Fuselage box | 1 | 3 mm birch aircraft plywood (sides, floor, bulkheads, rear wall), 6 mm birch aircraft plywood (firewall and wing-root doublers), 80 g/m2 glass cloth and epoxy outside; 750 x 156 x 150 mm (140 mm wide before decision 10A, so the Kitewright Core has 150 mm inside); floor cut with the Core's 200 x 112 mm lid opening and four 4.3 mm holes on a 220 x 130 mm pattern; rear bulkhead at 645 mm; Core deck doubler of 6 mm birch, 300 x 150 mm, with the same opening and holes and four M4 T-nuts | Model aircraft plywood and composites supplier | 51.00 | make | Indicative price for the plywood share and resin; joiner and wing bolt holes drilled through sides and doublers (KWR-DDR-002); USD 2 more for the wider sheets and USD 4 for the doubler and T-nuts (same supplier, priced by area and per piece)
2 Hatch | 1 | 3 mm birch aircraft plywood 750 x 156 mm, front tongue, one M4 nylon thumb screw into a captive nut, 8.5 mm hole for the GNSS mast (the Core's GNSS receiver on top), three 6.5 mm holes for the Core's antennas on extension leads | Cut from the sheets in item 1 | 4.00 | make | Indicative price for the thumb screw and nut
3 Nose cone and cruise motor mount | 1 | Printed ASA, about 120 g, 4 perimeters, 25 % gyroid infill; four M3 heat-set inserts for the cruise motor on a 25 mm bolt circle (to match the motor bought); bonded and bolted to the firewall with four M4 bolts | 3D printing filament supplier | 8.00 | make | Indicative price
4 Tail boom socket | 1 | Printed ASA, about 60 g, 6 perimeters, 40 % infill, 20 mm bore, split clamp with one M4 x 30 bolt; glued to the rear wall and floor | 3D printing filament supplier | 4.00 | make | Indicative price
5 Wing panel with aileron | 2 | XPS foam 30 kg/m3 hot-wire cut to NACA 2412, root chord 310 mm, tip chord 250 mm, 1,180 mm panel; 80 g/m2 glass cloth both sides in epoxy; 3 mm plywood root rib with the joiner and wing bolt holes; two 3 mm plywood pylon hardpoints; 10 mm wiring conduit; aileron hinged on tape; servo bay | Foam, glass and epoxy from a composites supplier | 70.00 | make | Indicative price per panel
6 Wing spar | 2 | Pultruded carbon tube 22 mm OD, 20 mm ID, 1,200 mm long, cut to 1,160 mm | Carbon tube supplier | 38.00 | buy | Indicative price
7 Wing joiner tube | 1 | Roll-wrapped carbon tube 20 mm OD, 16 mm ID, 640 mm long; slides into both spars | Carbon tube supplier | 35.00 | buy | Indicative price; check it slides in the spar bore without play when bought
8 Wing bolt | 2 | M5 x 40 nylon socket cap screw with an M5 threaded insert bonded in the root rib | Fastener supplier | 1.00 | buy | Indicative price
9 Boom pylon | 2 | Printed ASA, about 150 g, 6 perimeters, 40 % infill, 200 x 44 x 90 mm, top shaped to the wing lower skin; four M4 heat-set inserts; two M5 captive nuts | 3D printing filament supplier | 8.00 | make | Indicative price
10 Pylon bolt | 4 | M5 x 90 stainless socket cap screw with a 15 mm penny washer on the upper skin | Fastener supplier | 1.50 | buy | Indicative price
11 Boom clamp cap | 4 | Printed ASA, 100 % infill, 30 x 44 mm, two M4 x 20 bolts each | 3D printing filament supplier | 1.50 | make | Indicative price
12 Lift boom | 2 | Roll-wrapped carbon tube 25 mm OD, 23 mm ID, 1,200 mm long, cut to 1,142 mm | Carbon tube supplier | 52.00 | buy | Indicative price for a 1,200 mm tube (USD 4 more than the 1,100 mm tube); 50 mm longer for the 22 in propellers (KWR-DDR-003)
13 Landing leg set | 4 | Carbon rod 12 mm x 182 mm; printed ASA boom clamp (two M3 bolts); printed ASA elliptical fairing 32 x 16 mm; printed TPU foot 36 mm | Carbon and filament suppliers | 9.00 | make | Indicative price per leg
14 Tail boom | 1 | Pultruded carbon tube 20 mm OD, 17 mm ID, 900 mm long, cut to 850 mm | Carbon tube supplier | 28.00 | buy | Indicative price
15 Tail mount | 1 | Printed ASA, about 70 g, 6 perimeters, 40 % infill, shaped to the stabiliser and fin roots, split clamp with one M4 bolt | 3D printing filament supplier | 4.00 | make | Indicative price
16 Horizontal stabiliser with elevator | 1 | XPS foam hot-wire cut to NACA 0010, 640 x 170 mm, 80 g/m2 glass both sides, elevator hinged on tape at 70 % chord, servo bay | Composites supplier | 18.00 | make | Indicative price
17 Fin with rudder | 1 | XPS foam hot-wire cut to NACA 0010, root chord 170 mm, tip chord 130 mm, 300 mm high, glass both sides, rudder hinged on tape at 70 % chord | Composites supplier | 14.00 | make | Indicative price
18 Lift motor mount | 4 | Aluminium motor mount that clamps a 25 mm tube, top plate at least 64 mm across drilled for a 5215-class motor | Multirotor parts supplier | 18.00 | buy | Indicative price
19 Lift ESC | 4 | 60 A, 6S, open-firmware (AM32 or BLHeli-32 class), DShot, rated to -20 C or tested cold | Multirotor parts supplier | 45.00 | buy | Indicative price; strapped under the boom inboard of the motor
20 Lift motor | 4 | 5215-class outrunner, about 260 to 300 KV, 6S, about 285 g, 62 mm can, maker static thrust at least 7.0 kgf with a 22 x 7 in propeller at sea level | Multirotor motor supplier | 150.00 | buy | Indicative price from maker-class 5215 motors (USD 30 more than the 5212 class, KWR-DDR-003); thrust at 5000 m density to be measured in AltiRig
21 Lift propeller | 4 | 22 x 7 in carbon, about 55 g, two clockwise and two anticlockwise | Multirotor parts supplier | 50.00 | buy | Indicative price from maker-class 22 in carbon propellers (USD 10 more than the 20 in, KWR-DDR-003)
22 Cruise motor and ESC | 1 | 4120-class outrunner, 400 KV, about 195 g, with a 60 A 6S ESC | Fixed-wing parts supplier | 130.00 | buy | Indicative price
23 Cruise folding propeller | 1 | 14 x 10 in folding blades on a 36 mm spinner and yoke | Fixed-wing parts supplier | 35.00 | buy | Indicative price
24 Servo | 4 | Metal-gear digital servo, 20 mm class, at least 0.5 N m, rated to -20 C or tested cold (2 ailerons, elevator, rudder) | Fixed-wing parts supplier | 35.00 | buy | Indicative price
25 Heated pitot probe and airspeed sensor | 1 | Pitot-static probe 6 mm with a heater, differential pressure sensor on the Kitewright Core bus | Autopilot parts supplier | 140.00 | buy | Indicative price
26 Kitewright Core | 1 | Kitewright Core to KWC-DWG-001 Rev P2 (decision 10A): 240 x 150 mm carbon plate hung under the fuselage floor at the centre of gravity on four 8 mm corner spacers (M4, 220 x 130 mm), lid 168 x 92 mm up through the 200 x 112 mm floor opening; autopilot, GNSS and compass, radios, power board; its GNSS receiver rides the hatch mast and its three antennas sit on the hatch on extension leads | See kitewright-core bom/bom.csv | 900.00 | buy | Range's share of the Kitewright Core; 0.99 kg with its rail and pins (Core R9, KWC-DDR-003), in place of the 180 x 110 x 60 mm, 0.78 kg box assumed before
27 Core payload rail (Kitewright Core) | 1 | The Kitewright Core's plain rail, front stops, two locking pins and DS-014 pigtail under its plate; payloads slide in from the tail on a 184 x 128 x 5 mm payload shoe (KWC-DWG-106) | See kitewright-core bom/bom.csv | 60.00 | buy | Range's share of the Core kit; mass in item 26; replaces the 160 x 80 x 12 mm plate assumed before
28 ColdCell pack | 2 | 6S3P Li-ion, high-rate 21700 cells of 5.0 Ah, about 324 Wh, film heater with BMS thermostat, AS150 lead (family interface, decision 10A; XT90 before); 138 x 75 x 82 mm, 1.40 kg | ColdCell design (Kitewright family) | 350.00 | buy | Assumed ColdCell format (cross-repo assumption); 5.0 Ah cells at about USD 3.30 more per cell than 4.5 Ah, USD 60 more per pack (KWR-DDR-003); AS150 in place of XT90 at the same price class
29 Power harness and connectors | 1 | 10 and 12 AWG silicone wire, AS150 connectors on every pack and bus lead (decision 10A; XT90 before), XT60 on the boom root plugs, arming plug in the main lead; three 300 mm SMA extension leads that take the Core's antennas to the hatch | Electronics distributor | 100.00 | buy | Indicative price; the antenna leads add USD 15 (hobby RF supplier, about USD 5 each)
30 Fasteners and consumables | 1 | M3, M4 and M5 bolts and heat-set inserts, epoxy, cyanoacrylate, hinge tape, cable ties | Fastener and hobby suppliers | 60.00 | buy | Indicative price
31 Transport case | 2 | Hard case with foam, inside length at least 1,250 mm, no more than 1,300 mm outside | Case supplier | 180.00 | buy | Indicative price
32 Arming switch | 1 | Lockable safety switch on the hatch wired to the flight controller, plus the arming plug in item 29 | Autopilot parts supplier | 25.00 | buy | Indicative price
33 Core power leads | 1 | 8 AWG silicone wire, red and black, 2 m; four AS150 anti-spark connector halves (two pack inputs, two frame outputs, opposite genders); heat-shrink; soldered to the Kitewright Core's pads at integration and labelled PACK 1, PACK 2, FRAME A, FRAME B; about 124 g | Drone parts supplier | 60.00 | buy | Price basis: the Kitewright Core BOM line 21 (USD 60), which moves to each frame under Core decision 33B; now supplied by Range

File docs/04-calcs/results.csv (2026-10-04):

quantity | value
mtow_kg | 11.35
empty_kg | 10.35
x_cg_mm | 415.3
x_cg_target_mm | 414.4
cg_frac_mac | 0.2832
span_m | 2.516
wing_area_m2 | 0.7092
aspect_ratio | 8.926
wing_loading_n_m2 | 157
cd0 | 0.08336
cda_m2 | 0.05911
ld_cruise | 7.156
v_stall_ms | 18.12
v_cruise_ms | 22.65
cl_cruise | 0.832
p_cruise_aero_w | 352.5
p_cruise_elec_w | 676
hover_power_w | 1835
hover_current_a | 84.95
disc_loading_n_m2 | 113.5
thrust_max_5000_n | 165.1
hover_margin | 0.4825
sl_hover_thrust_frac | 0.4053
pack_wh | 324
nominal_wh | 648
usable_wh | 554
available_wh | 443.2
e_vtol_wh | 76.46
e_climb_wh | 22.4
cruise_wh | 344.4
endurance_min | 30.57
range_km | 41.54
spar_sf | 2.69
joiner_sf | 3.764
boom_sf | 8.425
tail_sf | 5.551
root_moment_nm | 73.92
boom_moment_nm | 30.98
pylon_bolt_n | 433.5
pylon_bolt_sf | 9.919
disc_below_wing_top_mm | 76.9
lift_cruise_disc_gap_mm | 32.84
rear_disc_to_te_mm | 43.66
vh | 0.5303
vv | 0.0245
boom_len_mm | 1142
panel_len_mm | 1205
cost_usd | 4314
cost_vs_target_usd | -686
pack_current_a_per_cell | 14.16
option B: two 6S4P packs of 5.0 Ah cells: mass | 12.23
option B: two 6S4P packs of 5.0 Ah cells: endurance | 38.43
option B: two 6S4P packs of 5.0 Ah cells: range | 54.2
option B: two 6S4P packs of 5.0 Ah cells: margin | 0.3758
option B: two 6S4P packs of 5.0 Ah cells: cost | 4554
option B: two 6S4P packs of 5.0 Ah cells: dcost | 240
option B: two 6S4P packs of 5.0 Ah cells: dmass | 0.88
option E: moulded carbon airframe: mass | 10.66
option E: moulded carbon airframe: endurance | 34.22
option E: moulded carbon airframe: range | 45.06
option E: moulded carbon airframe: margin | 0.5792
option E: moulded carbon airframe: cost | 5514
option E: moulded carbon airframe: dcost | 1200
option E: moulded carbon airframe: dmass | -0.695
option F: moulded carbon airframe and two 6S4P packs: mass | 11.54
option F: moulded carbon airframe and two 6S4P packs: endurance | 42.5
option F: moulded carbon airframe and two 6S4P packs: range | 58.22
option F: moulded carbon airframe and two 6S4P packs: margin | 0.4587
option F: moulded carbon airframe and two 6S4P packs: cost | 5754
option F: moulded carbon airframe and two 6S4P packs: dcost | 1440
option F: moulded carbon airframe and two 6S4P packs: dmass | 0.185

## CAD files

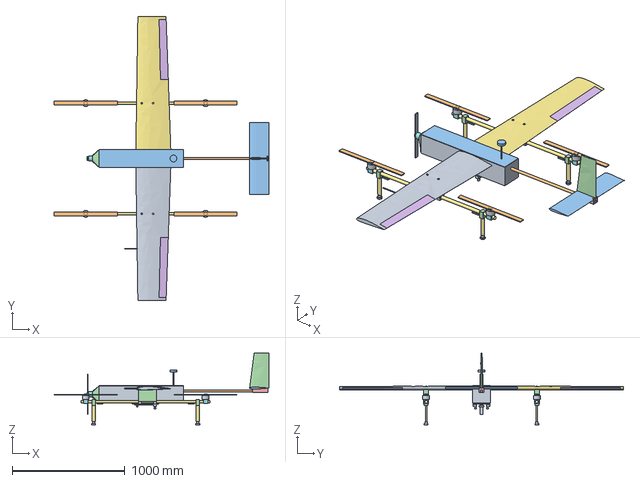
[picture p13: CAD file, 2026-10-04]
cad/step/kitewright-range-assembly.step
1901.0 x 2516.0 x 634.5 mm

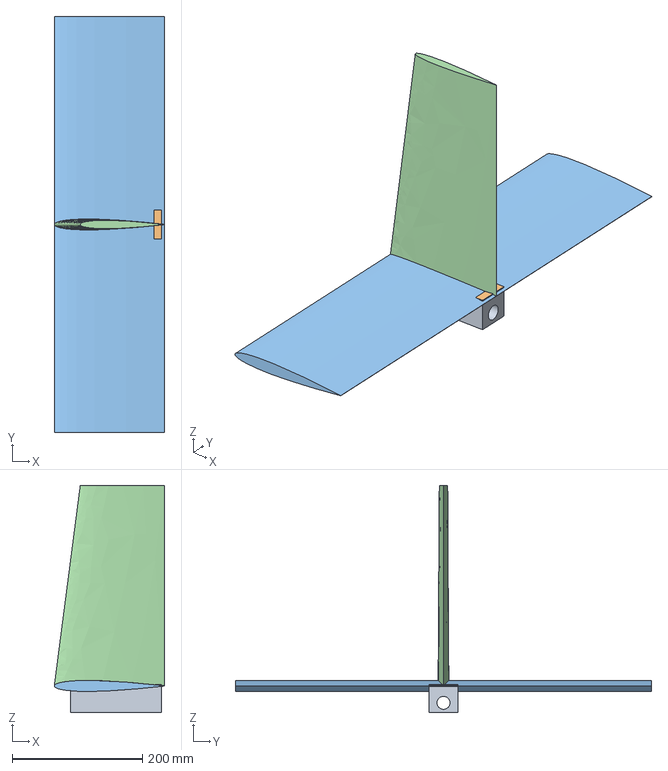
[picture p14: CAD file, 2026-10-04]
cad/step/kitewright-range-tail.step
170.0 x 640.0 x 349.5 mm

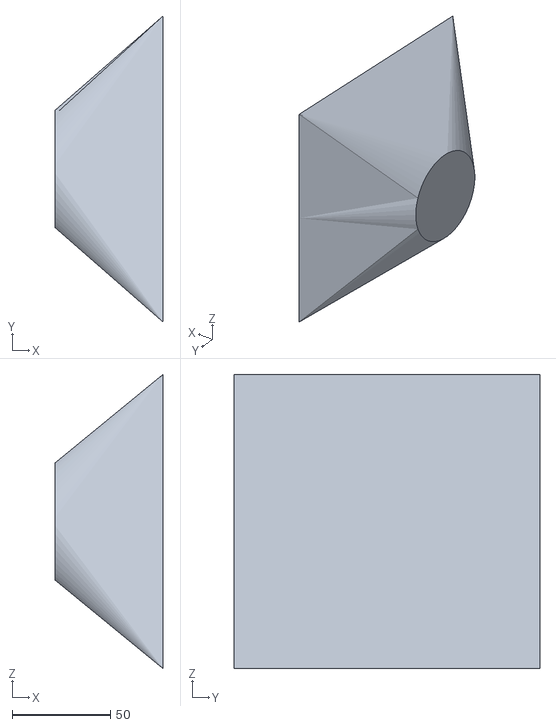
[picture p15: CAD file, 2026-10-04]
cad/stl/kitewright-range-nose-cone.stl
55.0 x 156.0 x 150.0

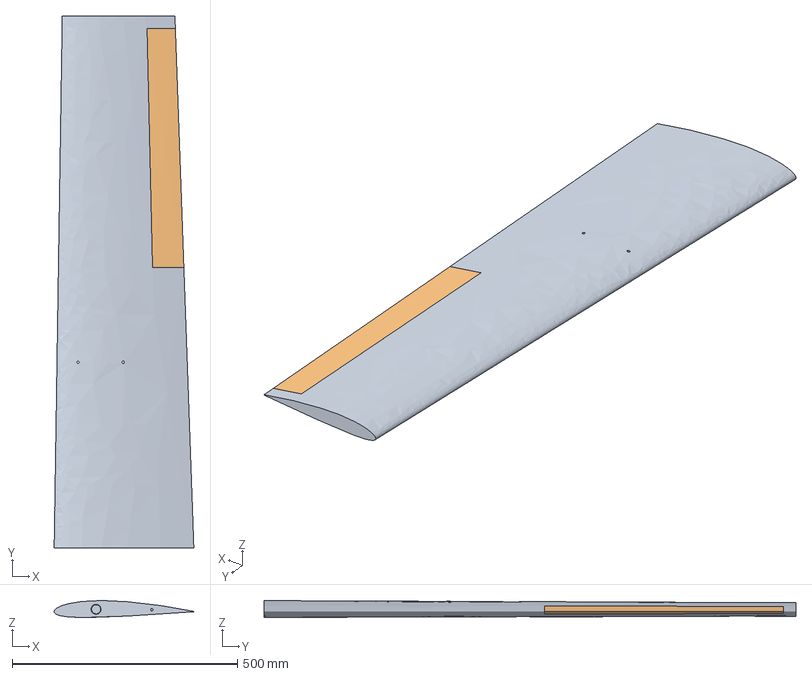
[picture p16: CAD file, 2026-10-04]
cad/step/kitewright-range-wing-panel-right.step
310.0 x 1180.0 x 37.7 mm

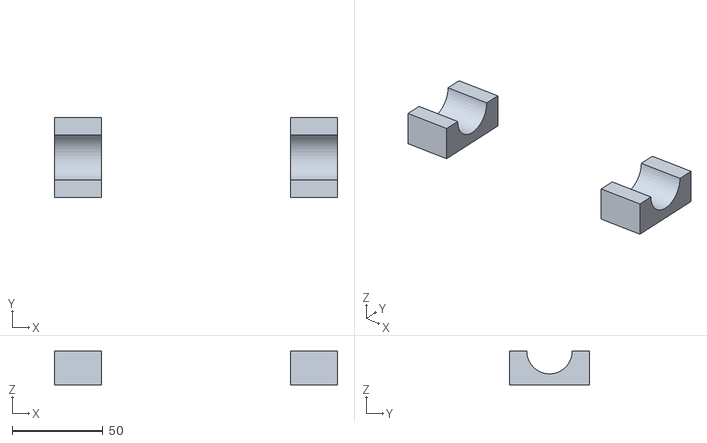
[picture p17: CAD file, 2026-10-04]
cad/stl/kitewright-range-boom-clamp-caps.stl
156.0 x 44.0 x 18.5

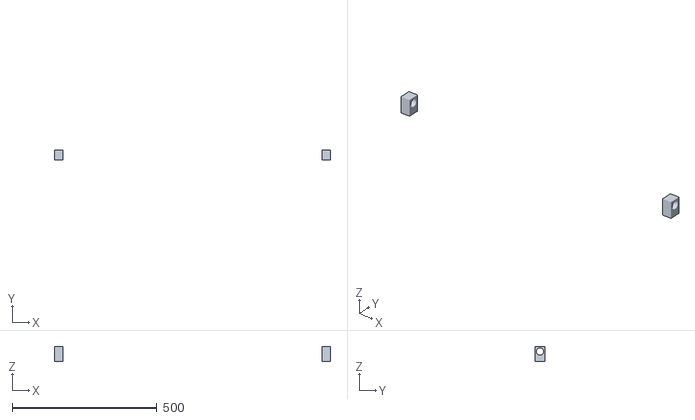
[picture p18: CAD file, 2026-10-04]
cad/stl/kitewright-range-leg-clamps.stl
952.0 x 36.0 x 52.0

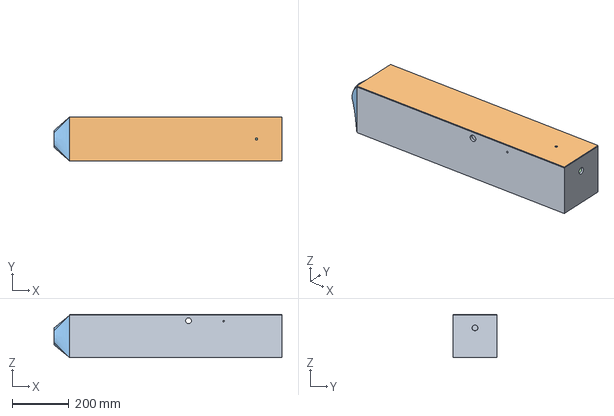
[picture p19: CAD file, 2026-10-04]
cad/step/kitewright-range-fuselage.step
805.0 x 156.0 x 153.0 mm

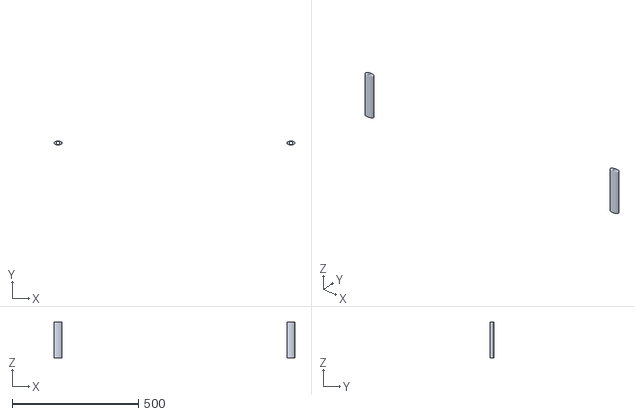
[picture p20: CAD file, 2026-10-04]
cad/stl/kitewright-range-leg-fairings.stl
954.0 x 16.0 x 142.5

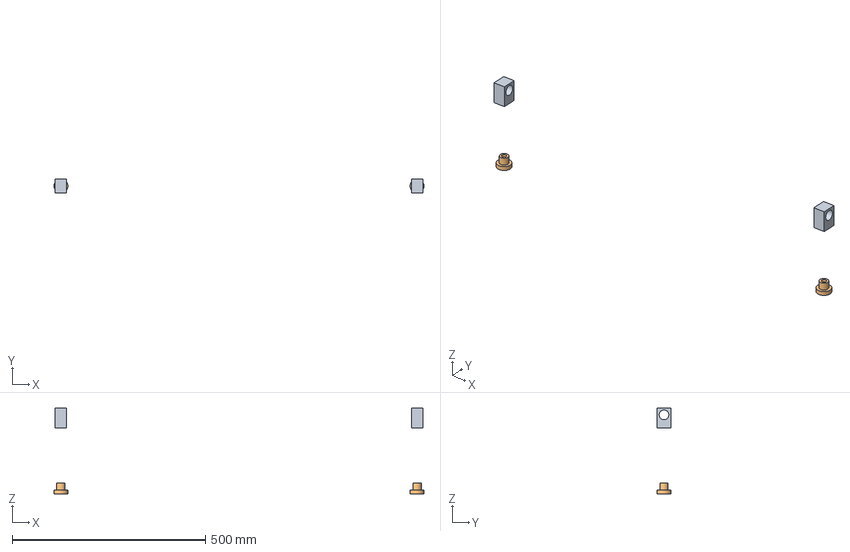
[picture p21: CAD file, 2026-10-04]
cad/step/kitewright-range-landing-leg-parts.step
958.0 x 36.0 x 222.5 mm

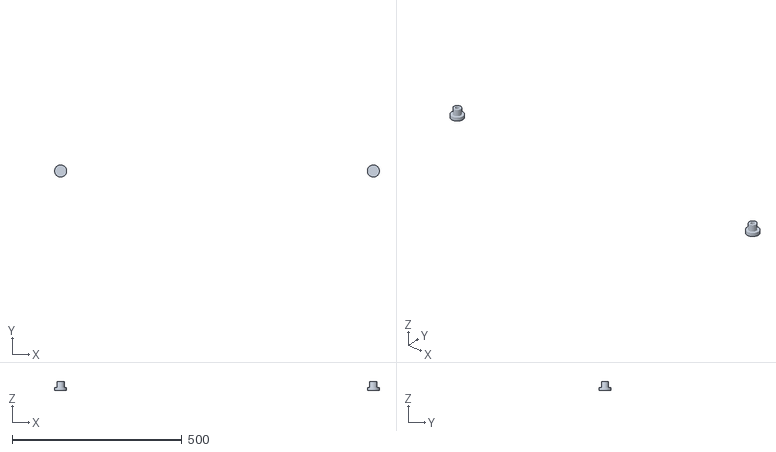
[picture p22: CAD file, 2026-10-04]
cad/stl/kitewright-range-landing-feet.stl
958.0 x 35.9 x 28.0

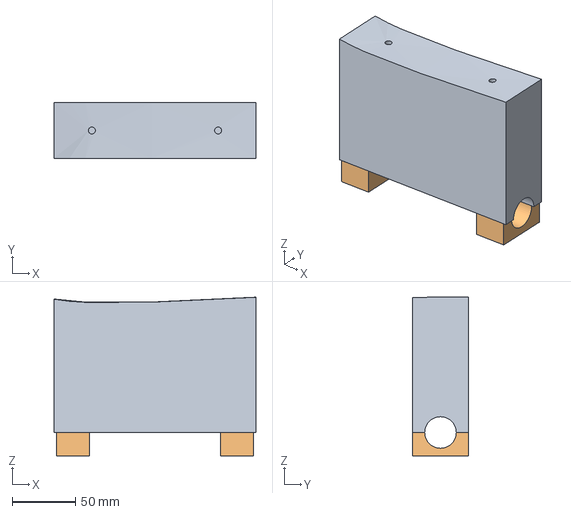
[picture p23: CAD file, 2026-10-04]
cad/step/kitewright-range-boom-pylon-right.step
160.0 x 44.0 x 125.7 mm

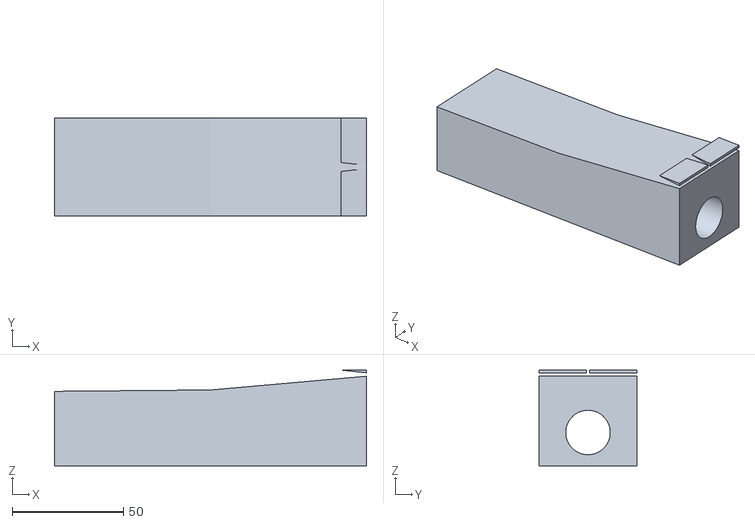
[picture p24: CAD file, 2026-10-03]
cad/stl/kitewright-range-tail-mount.stl
140.0 x 44.0 x 43.0

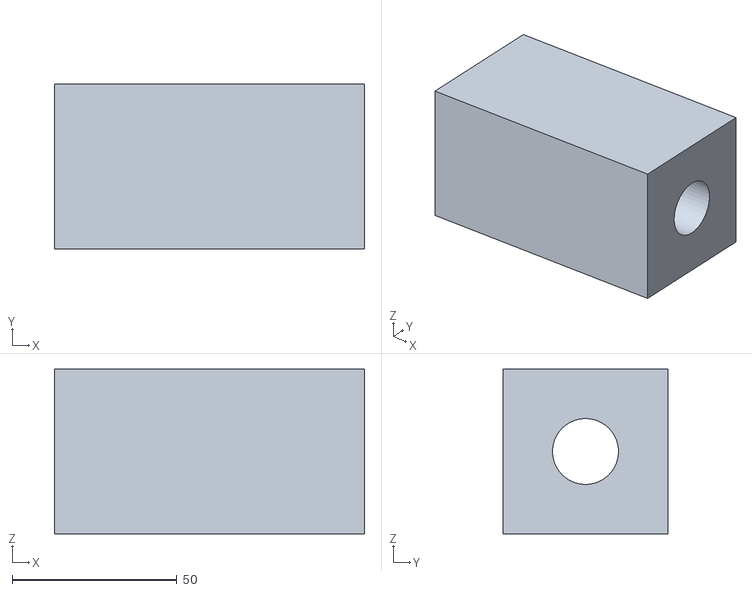
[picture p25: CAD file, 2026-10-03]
cad/stl/kitewright-range-tail-boom-socket.stl
94.0 x 50.0 x 50.0

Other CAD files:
cad/stl/kitewright-range-boom-pylon-right.stl

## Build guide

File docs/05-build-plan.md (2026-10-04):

---
doc_id: KWR-BLD-001
title: Kitewright Range prototype build plan
project: Kitewright Range
doc_type: Build plan
version: "0.3"
status: Draft
date: '2026-10-04'
author: Amish Chadha
license: CERN-OHL-S-2.0
revisions:
- version: "0.1"
  date: '2026-10-03'
  author: Amish Chadha
  change: First build plan; design made constructable (KWR-DDR-002)
- version: "0.2"
  date: '2026-10-03'
  author: Amish Chadha
  change: 'Amish''s 2026-10-03 decisions (KWR-DDR-003; "i agree with all the 46 recommendations you provided. please proceed."): 22 in propellers on 5215-class motors, longer booms further out, 5.0 Ah cells, Kitewright Core power leads made and fitted by Range'
- version: "0.3"
  date: '2026-10-04'
  author: Amish Chadha
  change: Amish's round-3 decision 10A (KWR-DDR-004); the Kitewright Core under the floor to the family envelope, 156 mm fuselage, Core deck doubler, packs moved, AS150, antennas and GNSS on the hatch; sections 1, 2, 3.1, 3.2, bought parts, steps 4, 5, 13, 14 and 16
---

# Kitewright Range prototype build plan

**Plan, not yet built.** How to build the first proof-of-concept prototype of the Kitewright Range quadplane, component by component. Building and testing to it is TRL 4 work. Decisions still to be made are kept in the design decisions register (`docs/06-design-decisions.md`), not here.

> **Safety:** This aircraft has four 22 in lift propellers, a 14 in cruise propeller and two lithium-ion packs of about 324 Wh each. Propellers go on only at the propeller safety stop (section 6), the arming plug stays out whenever anyone handles the aircraft, and packs are charged only between 0 and 45 °C in a fire-resistant box.

## 1. What you are building

Figure 1. Every component, pulled apart and numbered in build order

*Figure 1. Every component, pulled apart and numbered in build order.*

A 2.5 m span quadplane of about 11.4 kg with its 1 kg payload. Thirteen components are made: the fuselage box and hatch from plywood; the two wing panels, the stabiliser and the fin from hot-wire cut foam skinned in glass; the lift booms and tail boom cut from carbon tube; and the nose cone, tail socket, pylons, clamp caps, landing legs and tail mount printed in ASA. Everything else is bought: the lift and cruise motors with their ESCs and propellers, the servos, the pitot, the Kitewright Core with its payload rail, the four power leads that join the Core to the packs and the aircraft, and two ColdCell packs. The parts cost is estimated at USD 4,314 in the bill of materials.

## 2. What changed to make it buildable

| Component | The concept had | The buildable design has | Why |
| --- | --- | --- | --- |
| Tail | Carried on the lift booms | A conventional tail on its own carbon boom behind the fuselage | Booms stay short enough for the 1.3 m cases; the rear rotor wash stays off the tail |
| Lift booms | "Below the wing", no fixing | Printed pylons under the wing, through-bolted, with the booms held by clamp caps; booms 490 mm out from the centre line | The 22 in rotor discs sit 77 mm below the wing-top plane and 33 mm clear of the cruise propeller; the booms come off |
| Lift motors | Positions not set | 531 mm ahead of and behind the balance point on each boom | The rotors lift through the balance point and clear the wing |
| Cruise motor | Pusher or tractor | Tractor at the nose with a folding propeller | Nothing to clear behind; the blades fold for landing |
| Wing | Removable halves | Two panels on a carbon joiner through the fuselage, one nylon bolt each | A stock tube and a field-proven fixing |
| Fuselage | A pod | A plywood box 156 mm wide, with one pack in the nose bay and one behind the Kitewright Core's lid | Packs lift out with the wing fitted; balance does not change with the payload |
| Kitewright Core | An avionics box in front | The Core hung under the floor at the balance point to the family envelope (four M4 on 220 x 130 mm in a birch doubler, lid up through a 200 x 112 mm opening) | One Core fits Lift and Range the same way; the payload hangs on the balance point |
| Landing gear | None | Four faired legs on the booms | Stands level on rough ground with 80 mm under the payload |
| Wiring | Not shown | A conduit in each wing to a plug at the root | Boom power disconnects with the wing |

Every change is argued in decision record KWR-DDR-002. The propeller size, the cells and the Core power leads follow Amish's 2026-10-03 decisions, recorded in KWR-DDR-003; the Core's place, the fuselage width and the AS150 plugs follow his decision 10A of 2026-10-04, recorded in KWR-DDR-004.

## 3. Making the components

### 3.1 Fuselage box

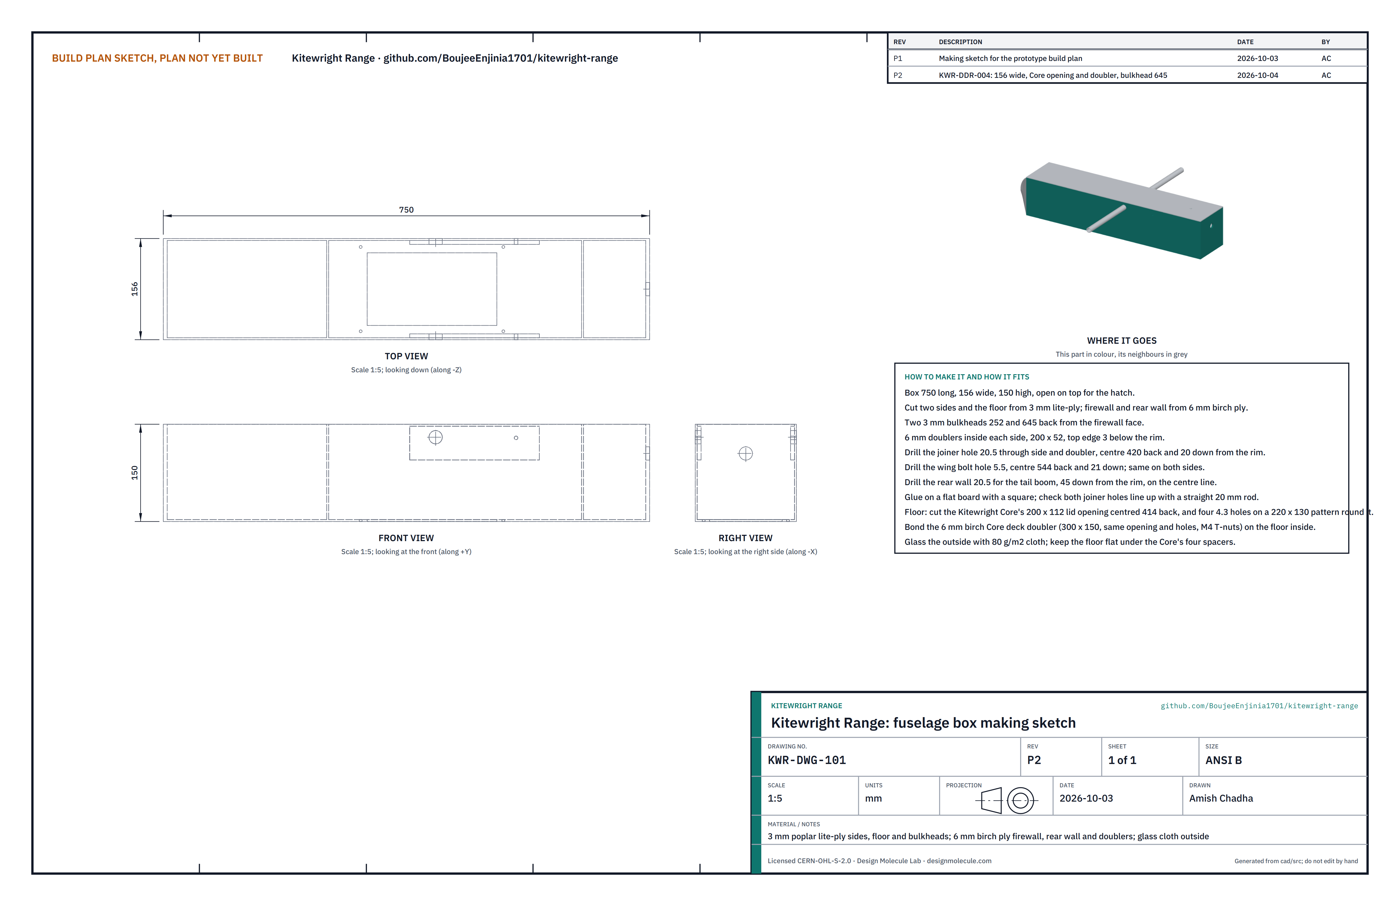
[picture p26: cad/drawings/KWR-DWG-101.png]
Figure 2. Fuselage box making sketch


*Figure 2. Fuselage box making sketch (KWR-DWG-101).*

**What it is and what it is made from.** An open-topped box 750 mm long, 156 mm wide and 150 mm high (150 mm inside, the width the Kitewright Core asks for). The sides, floor and two inner bulkheads are 3 mm poplar lite-ply; the firewall, the rear wall and two wing-root doublers are 6 mm birch ply. The outside is skinned in 80 g/m2 glass cloth.

**How to make it.**

1. Cut the two sides 750 x 150 mm and the floor 738 x 150 mm from 3 mm lite-ply; the firewall and rear wall 156 x 150 mm from 6 mm birch ply; two bulkheads 150 x 147 mm from 3 mm lite-ply.
2. Cut two doublers 200 x 52 mm from 6 mm birch ply. Glue one inside each side, 380 mm back from the front edge, with its top 3 mm below the side's top edge.
3. Clamp the two sides together and drill through both: a 20.5 mm hole 420 mm back and 20 mm down from the top edge (the wing joiner), and a 5.5 mm hole 544 mm back and 21 mm down (the wing bolt).
4. Drill a 20.5 mm hole in the rear wall on its centre line, 45 mm down from the top edge, for the tail boom.
5. Glue the box together on a flat board against a square: firewall at the front, rear wall at the back, bulkheads 252 mm and 645 mm behind the front face of the firewall.
6. Push a straight 20 mm rod through both joiner holes before the glue sets; it must slide freely and sit square to the sides.
7. Cut the Kitewright Core's 200 x 112 mm lid opening in the floor, centred 414 mm behind the firewall (the balance point), and drill four 4.3 mm holes on a 220 x 130 mm pattern round it. Glue the 6 mm birch Core deck doubler (300 x 150 mm, the same opening and holes) on the floor inside, and press four M4 T-nuts into it from above.
8. Sand the outside, lay 80 g/m2 glass cloth in epoxy, and glue a 3 mm lip inside the top of the firewall for the hatch tongue.

**How it fits the parts next to it.** The wing joiner runs through both sides and doublers (Figure 3). The nose cone glues and bolts to the firewall, the tail socket to the rear wall, and the hatch sits on the side walls and bulkheads.

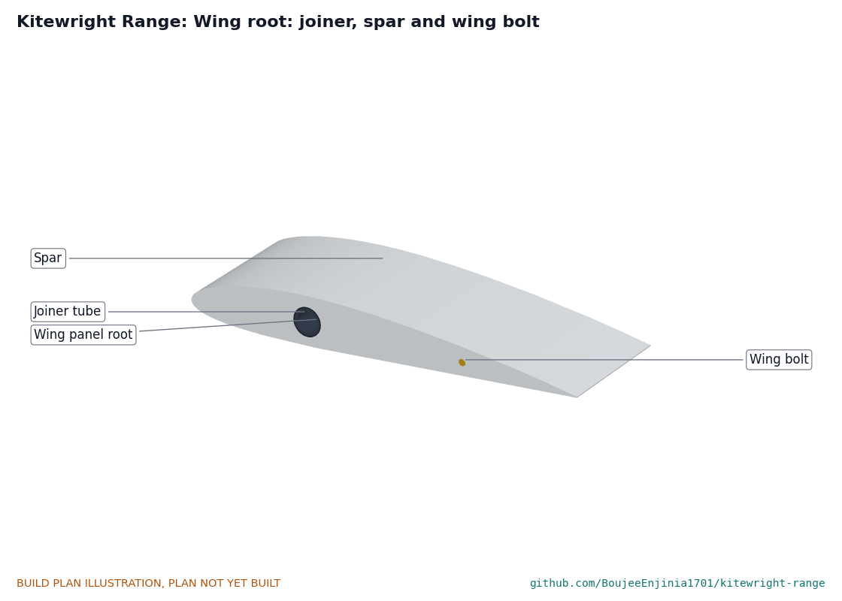
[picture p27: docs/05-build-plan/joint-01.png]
Figure 3. Wing root joint


*Figure 3. The joiner passes through the fuselage side and doubler into the spar; the nylon wing bolt goes from inside the fuselage into the root rib.*

**Check before moving on.** The box sits flat on a table without rocking; the rod slides through both joiner holes; the diagonals of the top opening match within 2 mm.

### 3.2 Hatch

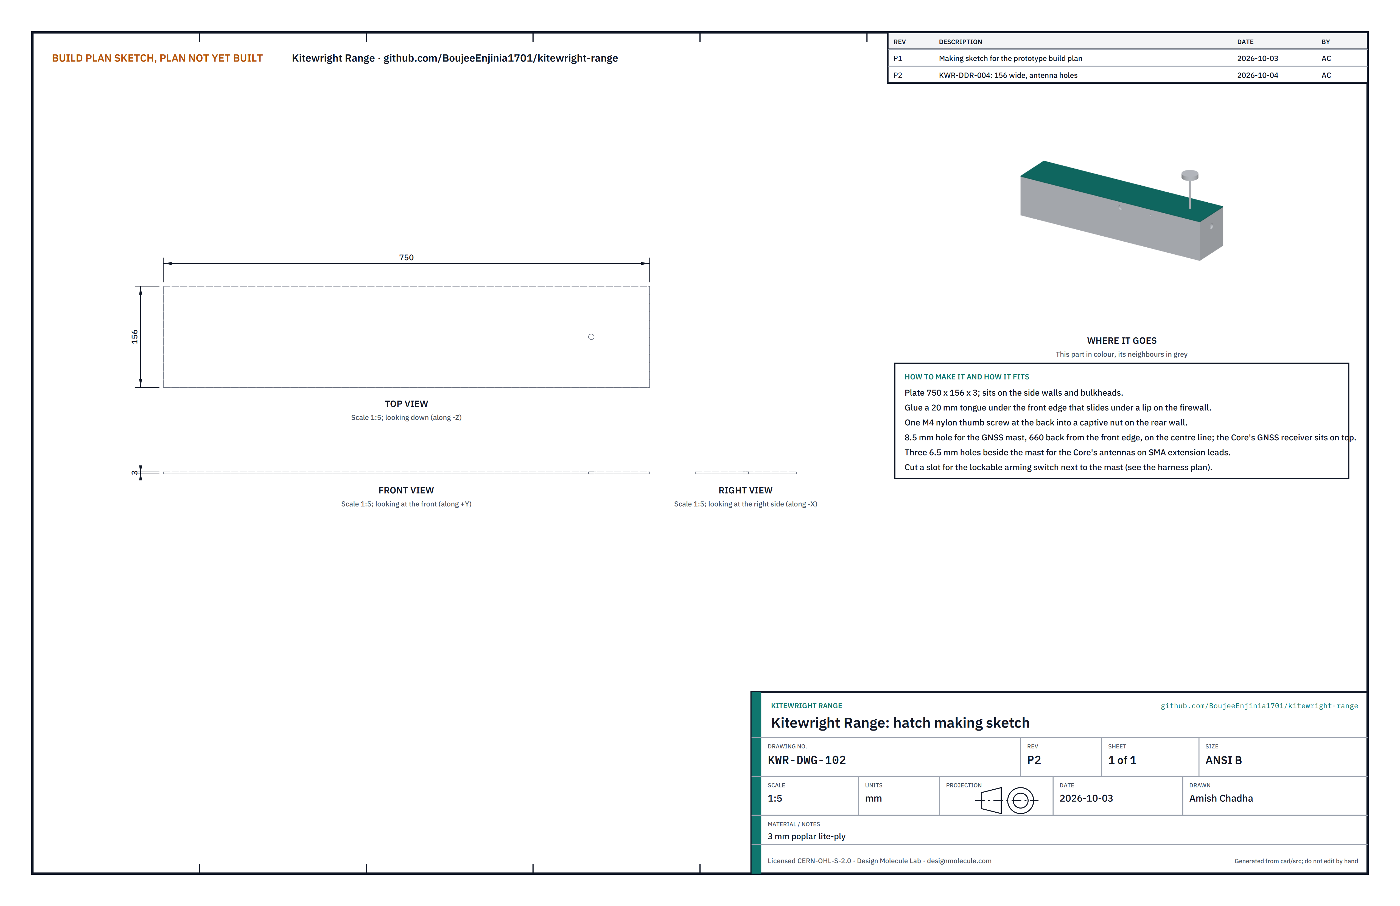
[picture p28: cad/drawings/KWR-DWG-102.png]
Figure 4. Hatch making sketch


*Figure 4. Hatch making sketch (KWR-DWG-102).*

**What it is and what it is made from.** A 750 x 156 mm lid of 3 mm lite-ply that carries the GNSS mast with the Core's GNSS receiver, the Core's three antennas and the arming switch.

**How to make it.**

1. Cut the plate 750 x 156 mm. Glue a 20 x 120 mm tongue under the front edge so it projects 10 mm forward.
2. Drill an 8.5 mm hole on the centre line 660 mm back from the front edge for the GNSS mast.
3. Cut the opening for the lockable arming switch beside the mast, to the switch bought, and drill three 6.5 mm holes beside the mast for the Core's antennas on SMA extension leads.
4. Drill the back for one M4 nylon thumb screw and glue a captive nut under the rear wall's top edge to match.

**How it fits the parts next to it.** The tongue slides under the lip on the firewall; the back is held by the thumb screw. The mast plugs through the hole into a socket glued to the rear bulkhead; the GNSS cable and the three antenna leads run down to the Core's lid.

**Check before moving on.** The hatch sits flat on all walls and comes off with the thumb screw alone.

### 3.3 Nose cone and cruise motor mount

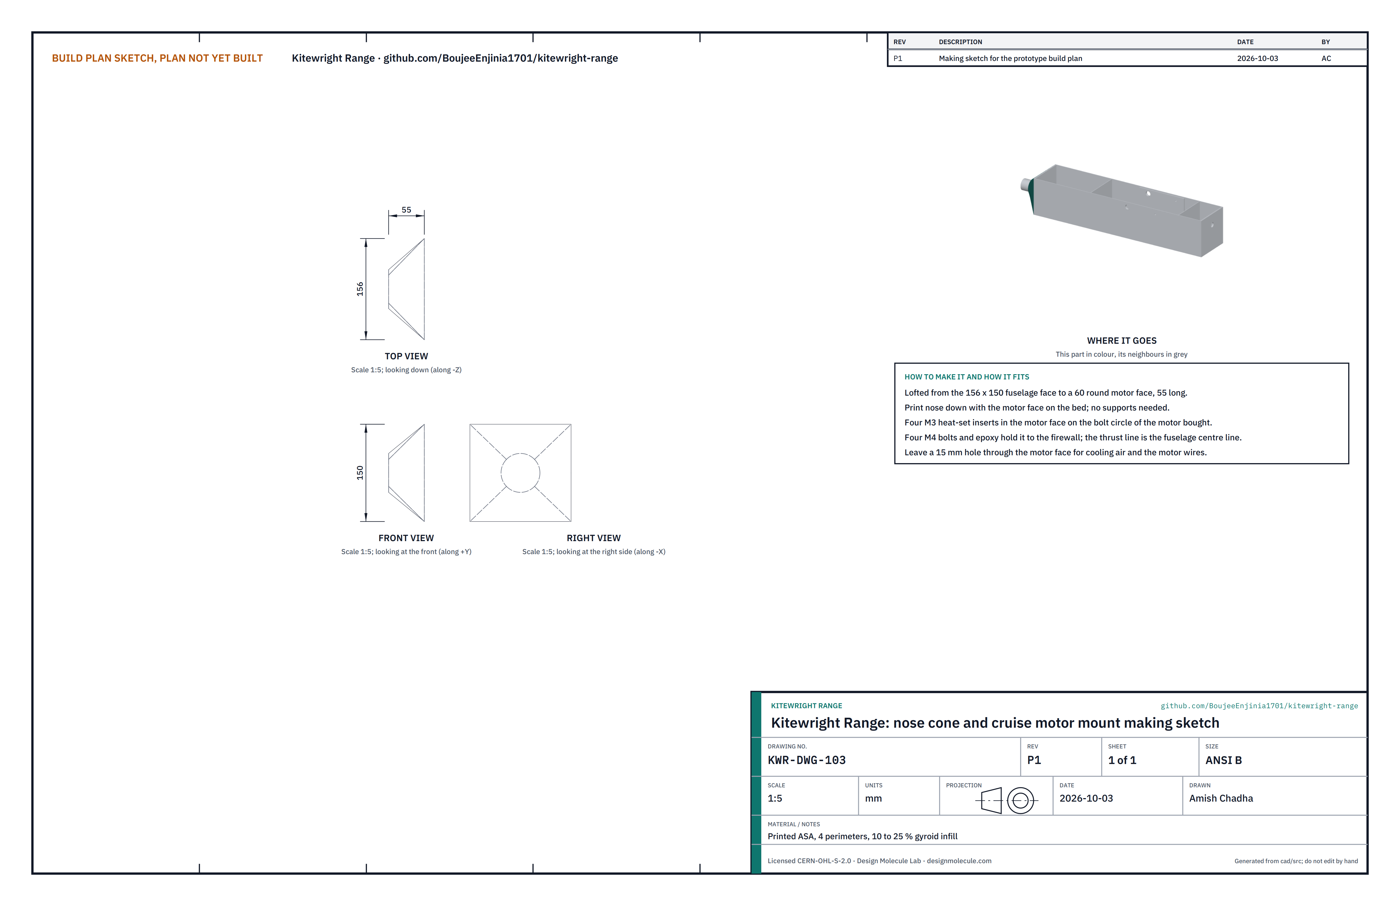
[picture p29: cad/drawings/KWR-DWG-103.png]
Figure 5. Nose cone making sketch


*Figure 5. Nose cone making sketch (KWR-DWG-103).*

**What it is and what it is made from.** A printed ASA cone 55 mm long that blends the 140 x 150 mm fuselage face into a 60 mm round motor face on the fuselage centre line.

**How to make it.**

1. Print with the motor face on the bed, four perimeters, 10 % gyroid infill; no supports.
2. Set four M3 heat-set inserts in the motor face on the bolt circle of the cruise motor bought, and open a 15 mm hole in the centre for air and wires.
3. Drill four 4.5 mm holes through the back flange to match four holes in the firewall.

**How it fits the parts next to it.** The back face glues to the firewall with epoxy and four M4 bolts (Figure 6). The cruise motor bolts to the front face.

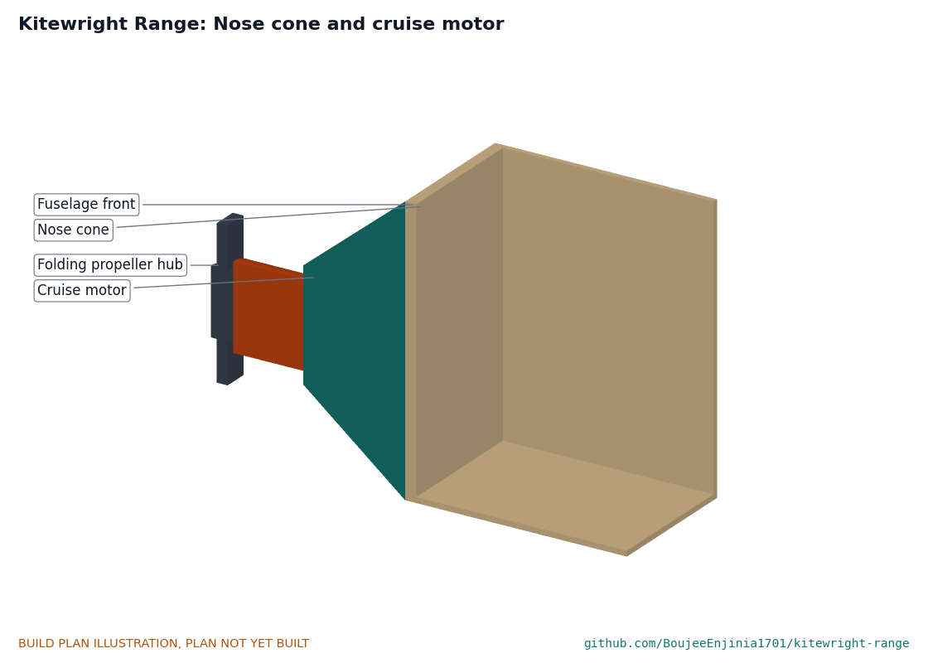
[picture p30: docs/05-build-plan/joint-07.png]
Figure 6. Nose joint


*Figure 6. Nose cone on the firewall and the cruise motor on its face, cut along the centre line.*

**Check before moving on.** A straightedge along the fuselage top and the motor axis are parallel; the motor face is square to the fuselage.

### 3.4 Tail boom socket

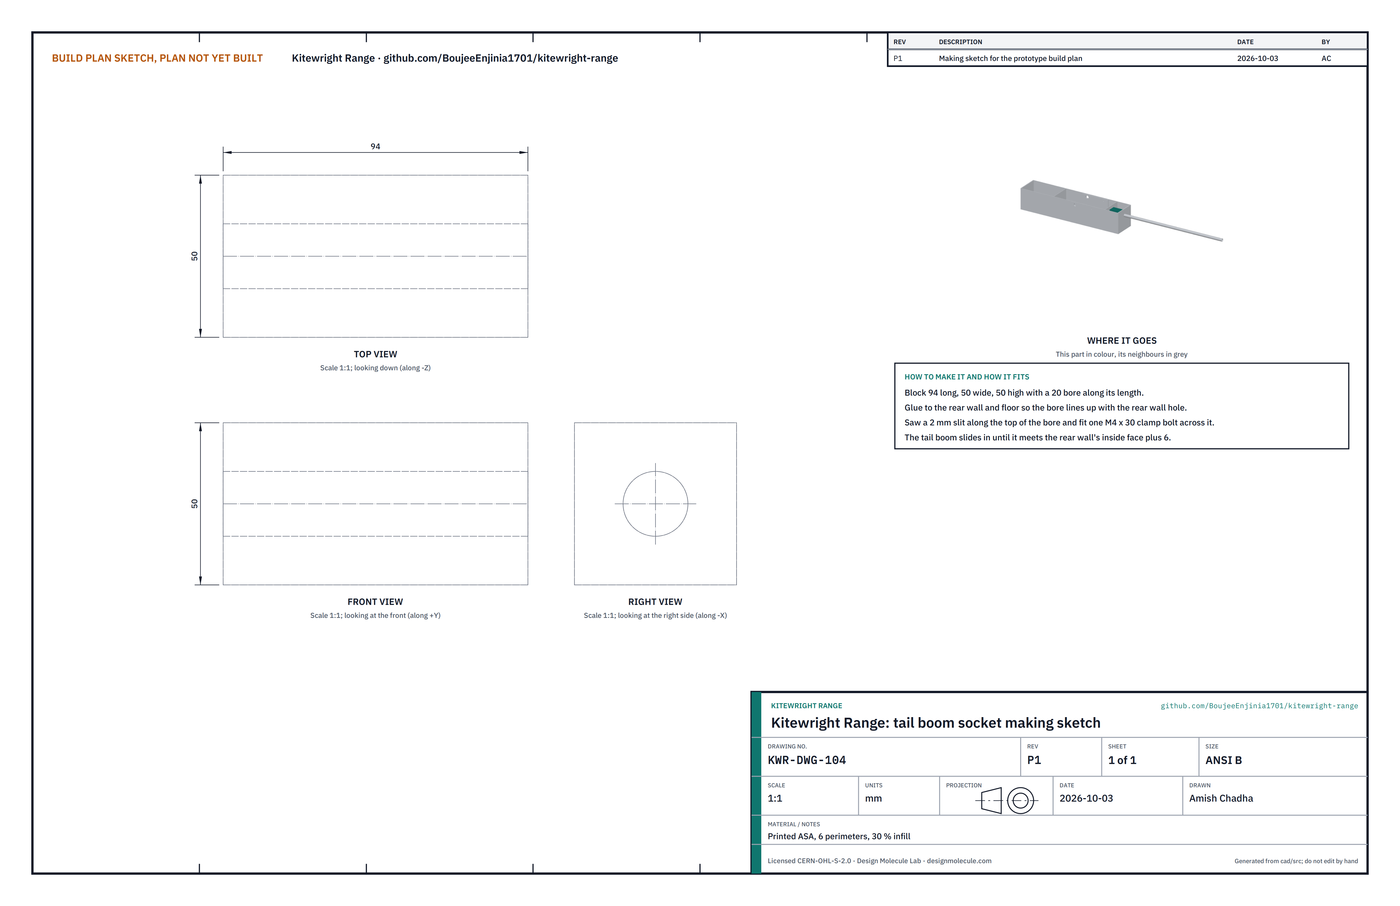
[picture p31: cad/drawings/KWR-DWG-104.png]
Figure 7. Tail boom socket making sketch


*Figure 7. Tail boom socket making sketch (KWR-DWG-104).*

**What it is and what it is made from.** A printed ASA block 94 x 50 x 50 mm with a 20 mm bore that holds the tail boom inside the back of the fuselage.

**How to make it.**

1. Print standing on its end, six perimeters, 30 % infill.
2. Saw a 2 mm slit along the top of the bore; drill across it for one M4 x 30 bolt and a nut.

**How it fits the parts next to it.** It glues to the rear wall and the floor with its bore lined up on the rear wall hole (Figure 8). The boom slides through the rear wall into the bore and the bolt clamps it.

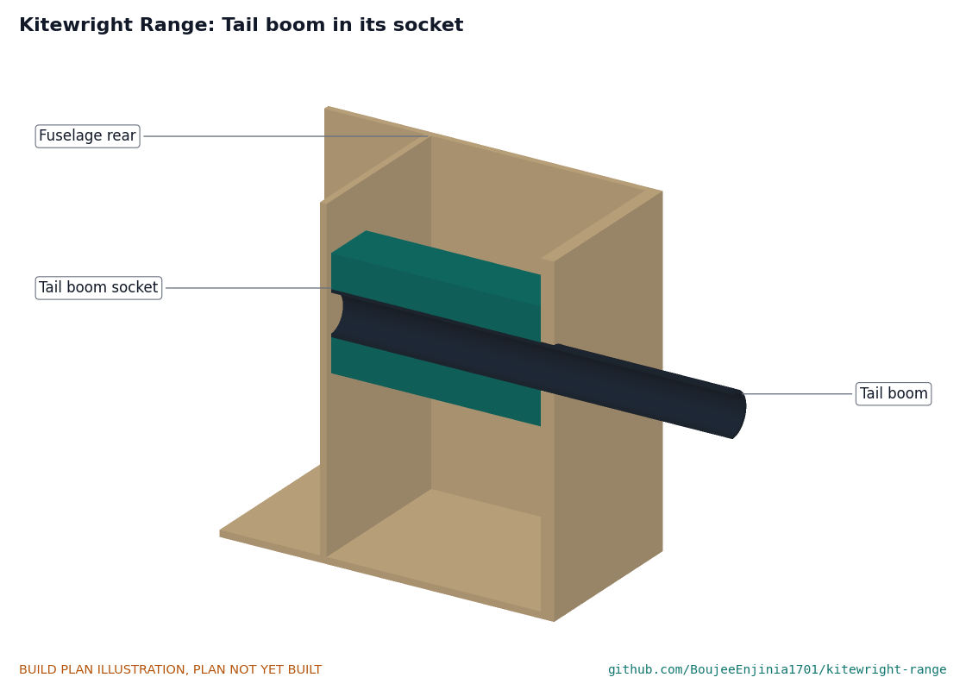
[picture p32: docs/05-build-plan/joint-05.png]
Figure 8. Tail boom socket joint


*Figure 8. Tail boom through the rear wall into the socket, cut along the centre line.*

**Check before moving on.** A 20 mm rod in the bore points straight back along the fuselage centre line, seen from above and from the side.

### 3.5 Wing panels (make a left and a right)

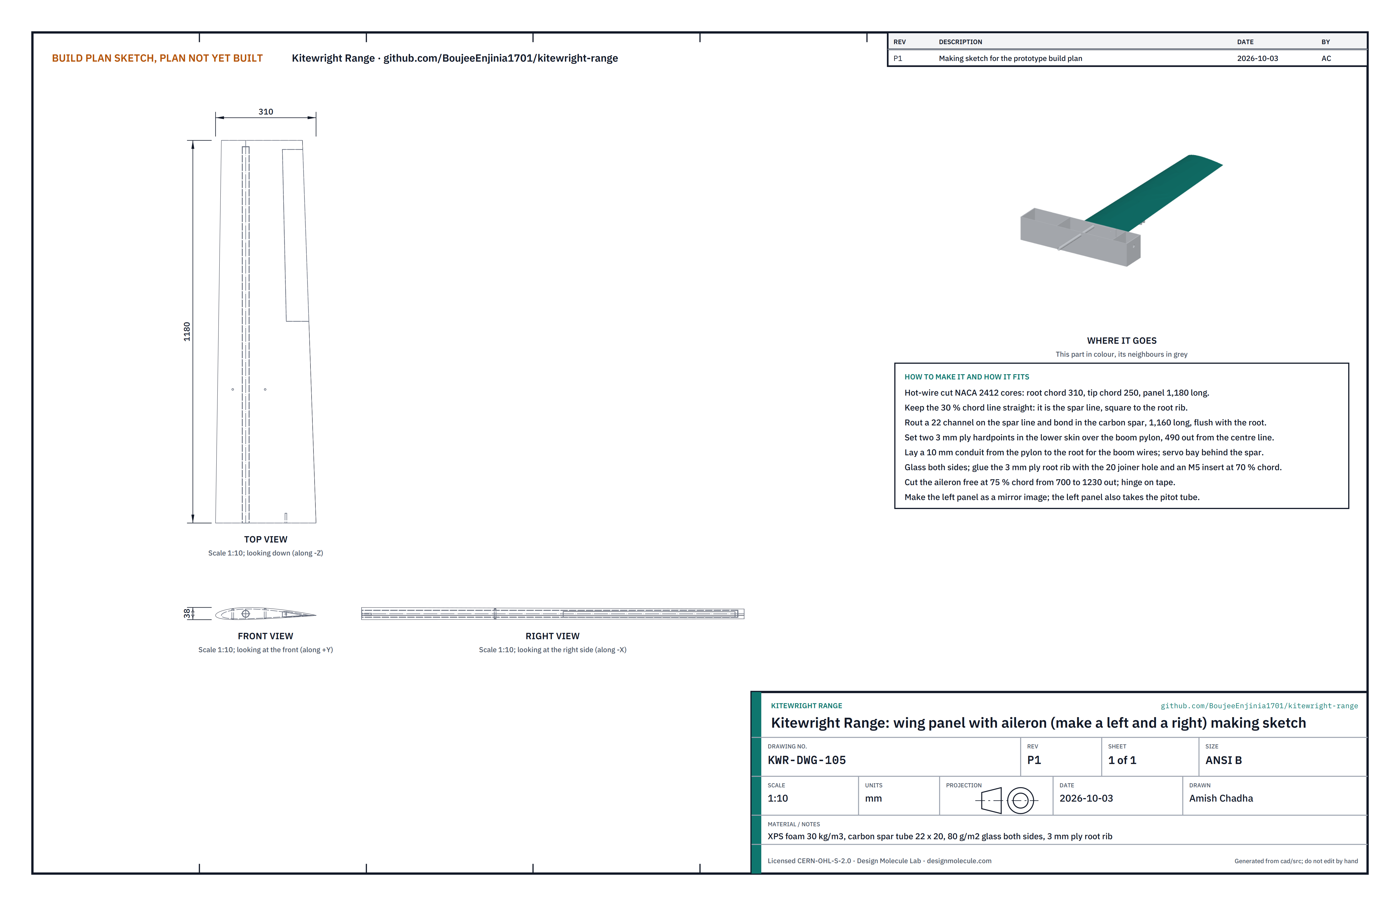
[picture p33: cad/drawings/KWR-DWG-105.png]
Figure 9. Wing panel making sketch


*Figure 9. Wing panel making sketch (KWR-DWG-105); the left panel is its mirror image.*

**What it is and what it is made from.** Each panel is 1,180 mm long, NACA 2412 section, 310 mm chord at the root and 250 mm at the tip. It is cut from 30 kg/m3 XPS foam, skinned both sides in 80 g/m2 glass, with a carbon spar 22 mm outside and 20 mm inside along the 30 % chord line, a 3 mm plywood root rib, two plywood hardpoints for the pylon and an aileron.

**How to make it.**

1. Hot-wire cut the core with root and tip templates, keeping the 30 % chord line straight and square to the root: it is the spar line.
2. Rout a 22 mm channel on the spar line and bond in the spar, cut to 1,160 mm, flush with the root.
3. Let two 3 mm plywood hardpoints, 60 x 50 mm, into the lower surface 490 mm from the aircraft centre line (420 mm from the root), one 40 mm ahead of the spar and one 60 mm behind it.
4. Lay a 10 mm conduit from the hardpoints to the root, and cut the aileron servo bay behind the spar.
5. Glass both sides in epoxy under vacuum or with peel ply.
6. Glue on the 3 mm plywood root rib, drilled 20.5 mm on the spar line and fitted with an M5 threaded insert at 70 % chord.
7. Cut the aileron free along the 75 % chord line from 700 mm to 1,230 mm out, and hinge it on tape.
8. For the left panel only: drill a 6 mm hole into the leading edge 800 mm out for the pitot tube.

**How it fits the parts next to it.** The joiner slides 250 mm into the spar; the root rib meets the fuselage side face to face, and the wing bolt pulls it tight (Figure 3). The boom pylon bolts under the hardpoints.

**Check before moving on.** Panel mass about 0.57 kg with spar and aileron; the spar bore takes the joiner; both panels have the same twist, checked with an incidence meter at root and tip.

### 3.6 Boom pylons (make 2)

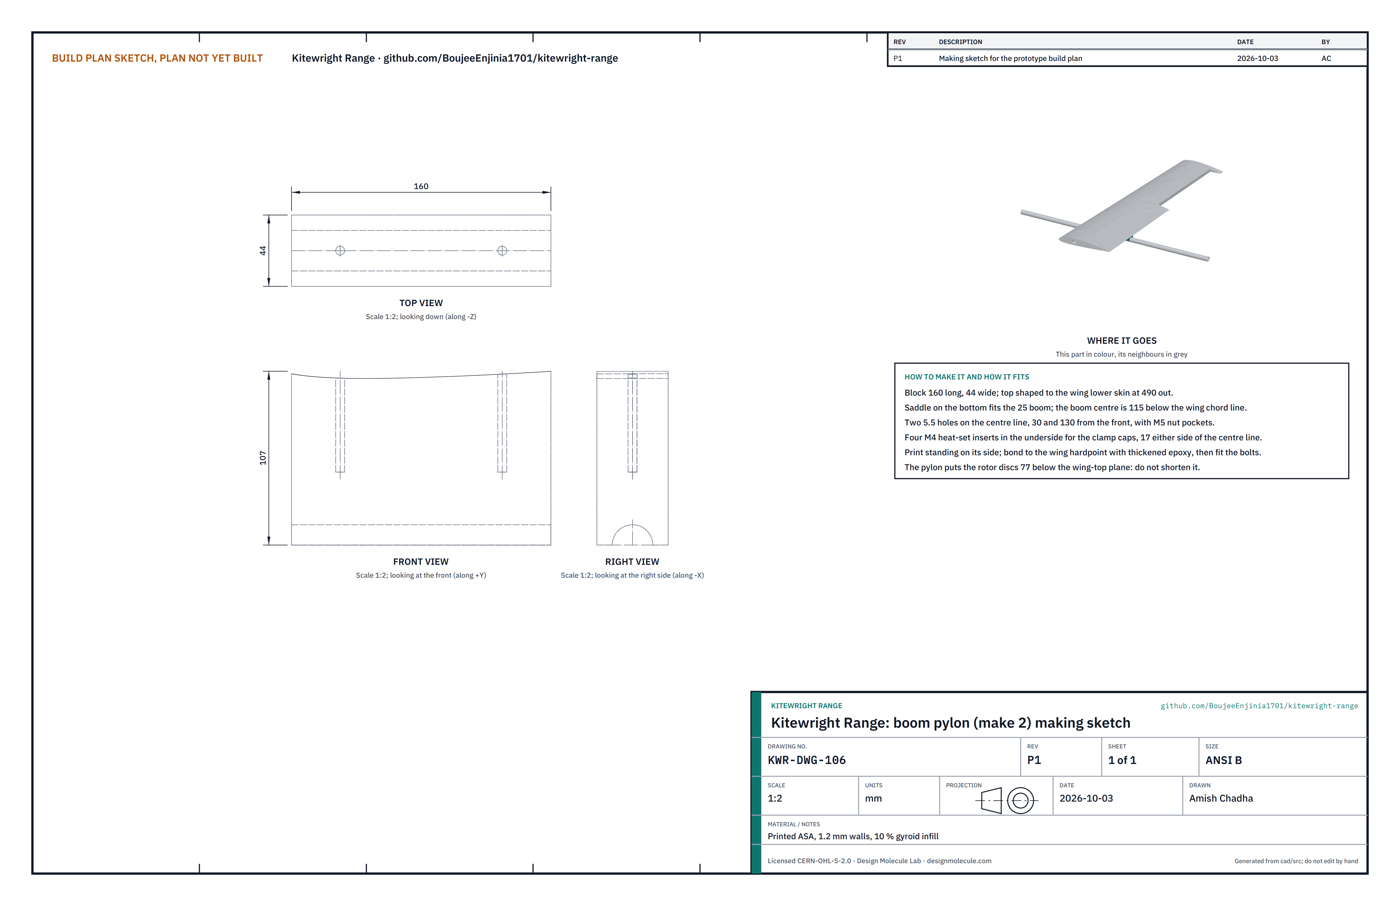
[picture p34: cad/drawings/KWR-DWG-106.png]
Figure 10. Boom pylon making sketch


*Figure 10. Boom pylon making sketch (KWR-DWG-106).*

**What it is and what it is made from.** A printed ASA block 160 mm long and 44 mm wide whose top follows the wing's lower skin and whose bottom is a half-round saddle for the 25 mm boom. It holds the boom 115 mm below the wing chord line.

**How to make it.**

1. Print on its side, 1.2 mm walls, 10 % gyroid infill.
2. Set four M4 heat-set inserts in the underside, 17 mm either side of the centre line, under each clamp cap.
3. Open the two 5.5 mm bolt holes, 30 mm and 130 mm from the front, and press an M5 nut into each nut pocket.

**How it fits the parts next to it.** It bonds to the hardpoints with thickened epoxy, and two M5 x 90 bolts come down through the wing from large washers on the upper skin into its nuts (Figure 11). The boom sits in the saddle, held by two clamp caps.

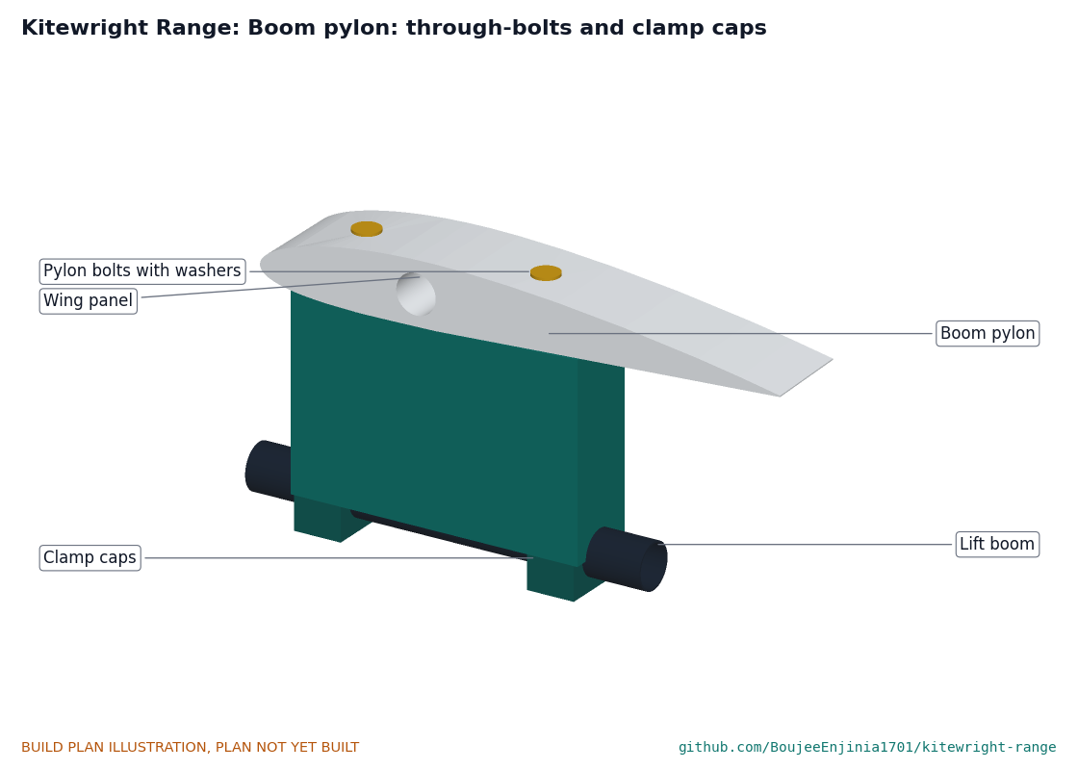
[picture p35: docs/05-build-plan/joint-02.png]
Figure 11. Pylon joint


*Figure 11. Pylon under the wing with its two through-bolts, and the boom held by two clamp caps, cut along the boom.*

**Check before moving on.** Both pylons are at the same distance from the root and their saddles are parallel to the fuselage, checked with a straight rod in each.

### 3.7 Boom clamp caps (make 4)

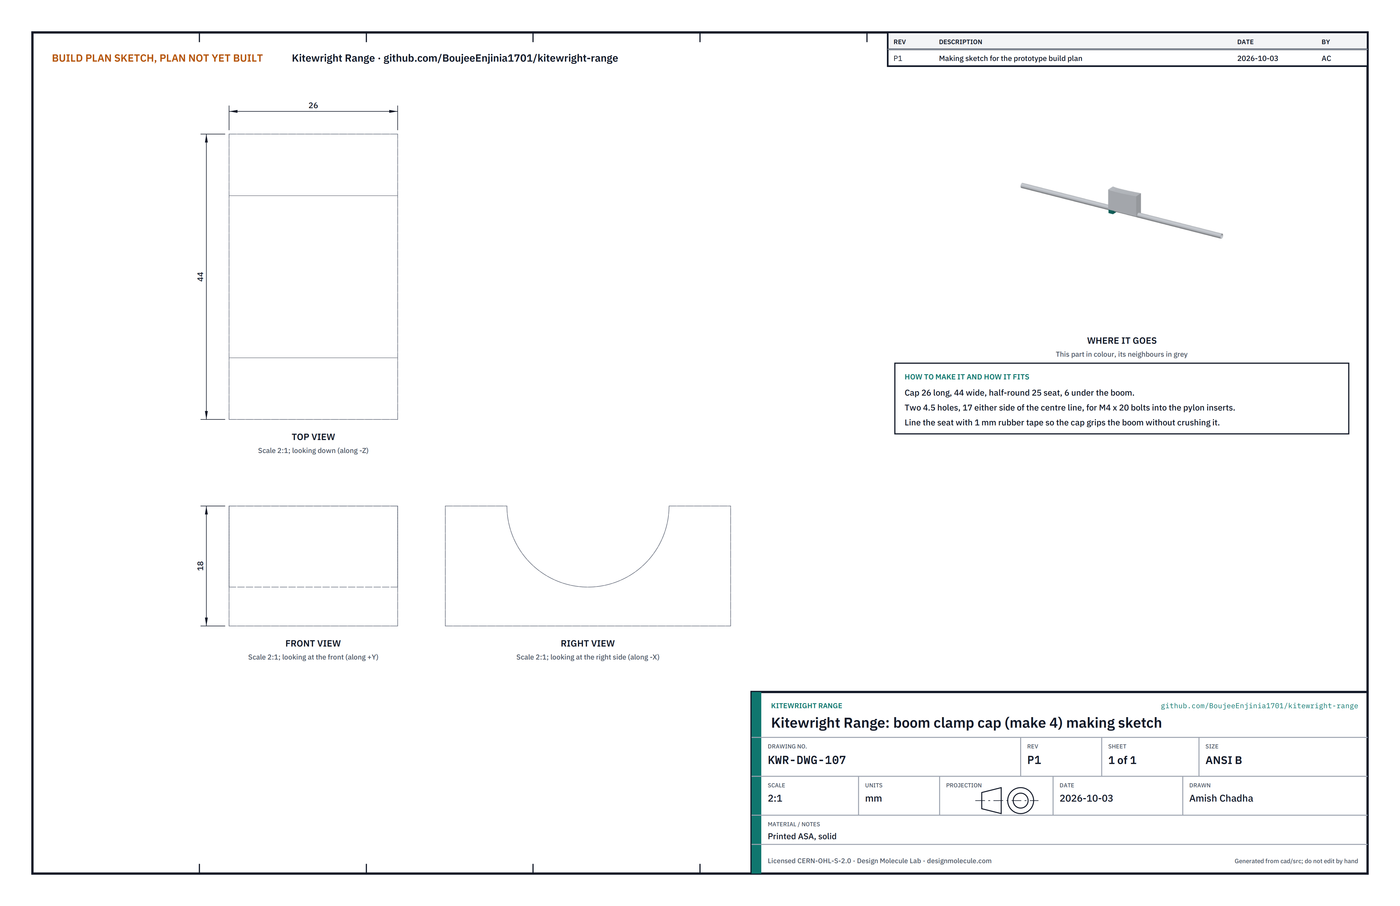
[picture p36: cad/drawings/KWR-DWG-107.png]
Figure 12. Clamp cap making sketch


*Figure 12. Clamp cap making sketch (KWR-DWG-107).*

**What it is and what it is made from.** A solid printed ASA cap 26 mm long and 44 mm wide with a half-round 25 mm seat, 6 mm thick under the boom.

**How to make it.** Print flat, 100 % infill. Drill two 4.5 mm holes 17 mm either side of the centre line. Line the seat with 1 mm rubber tape.

**How it fits the parts next to it.** Two M4 x 20 bolts pull it up into the pylon inserts, squeezing the boom into the saddle (Figure 11). Tighten until the boom will not turn by hand; do not crush the tube.

**Check before moving on.** The cap closes with a gap of about 1 mm to the pylon, so it grips before it bottoms.

### 3.8 Lift booms (make 2)

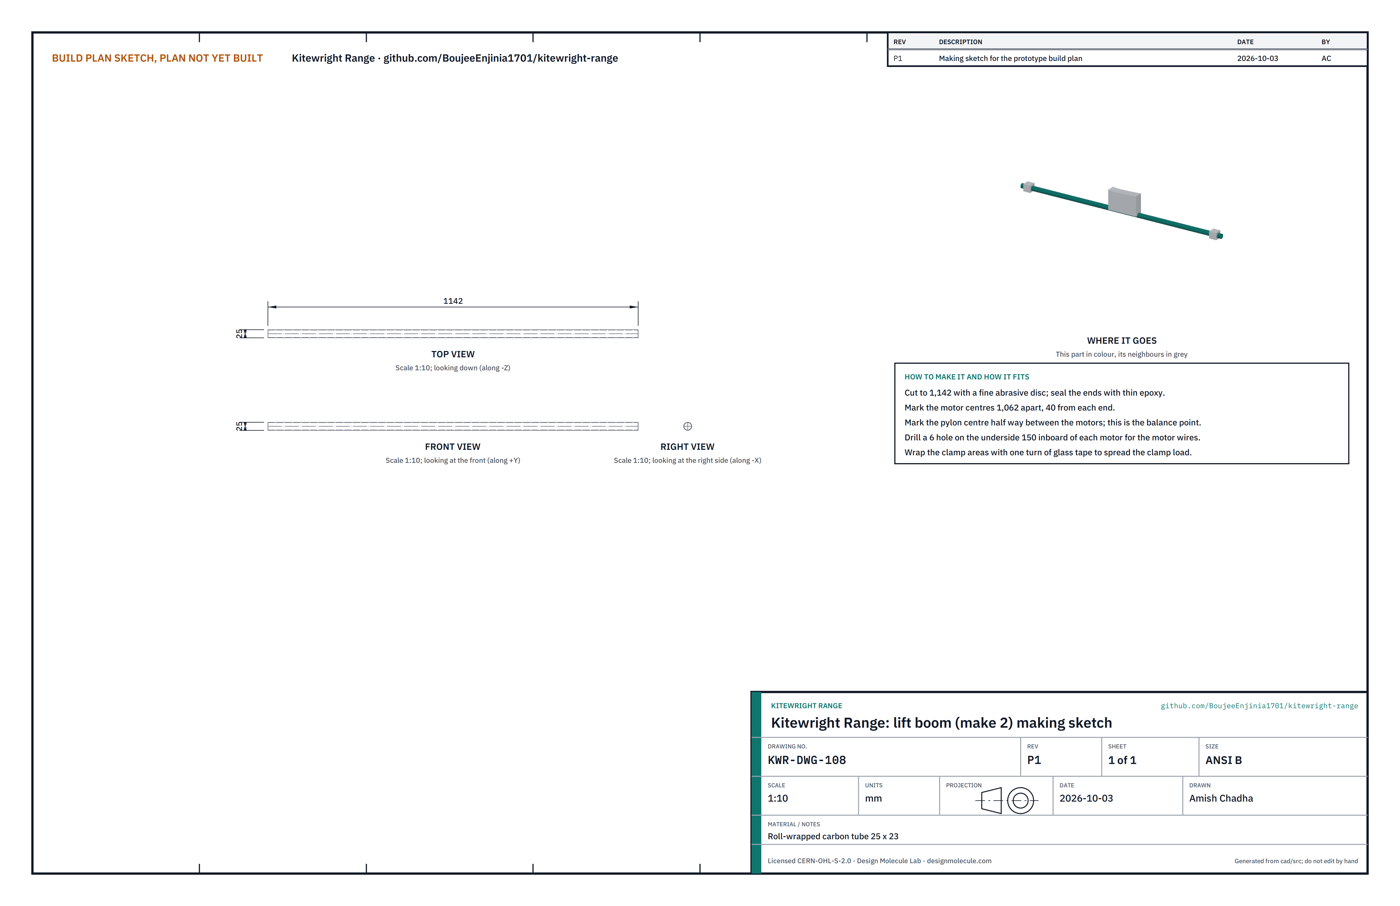
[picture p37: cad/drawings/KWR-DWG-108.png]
Figure 13. Lift boom making sketch


*Figure 13. Lift boom making sketch (KWR-DWG-108).*

**What it is and what it is made from.** Roll-wrapped carbon tube 25 mm outside, 23 mm inside, 1,142 mm long, cut from a 1,200 mm tube.

**How to make it.**

1. Cut to 1,142 mm with a fine abrasive disc; seal the ends with thin epoxy.
2. Mark the two motor centres 1,062 mm apart, 40 mm in from each end, and the pylon centre half way between them.
3. Drill a 6 mm hole on the underside 150 mm inboard of each motor for the motor wires.
4. Wrap the two clamp areas with one turn of glass tape.

**How it fits the parts next to it.** The middle sits in the pylon saddle; the motor mounts clamp each end (Figure 14); the landing legs clamp 70 mm inboard of each motor.

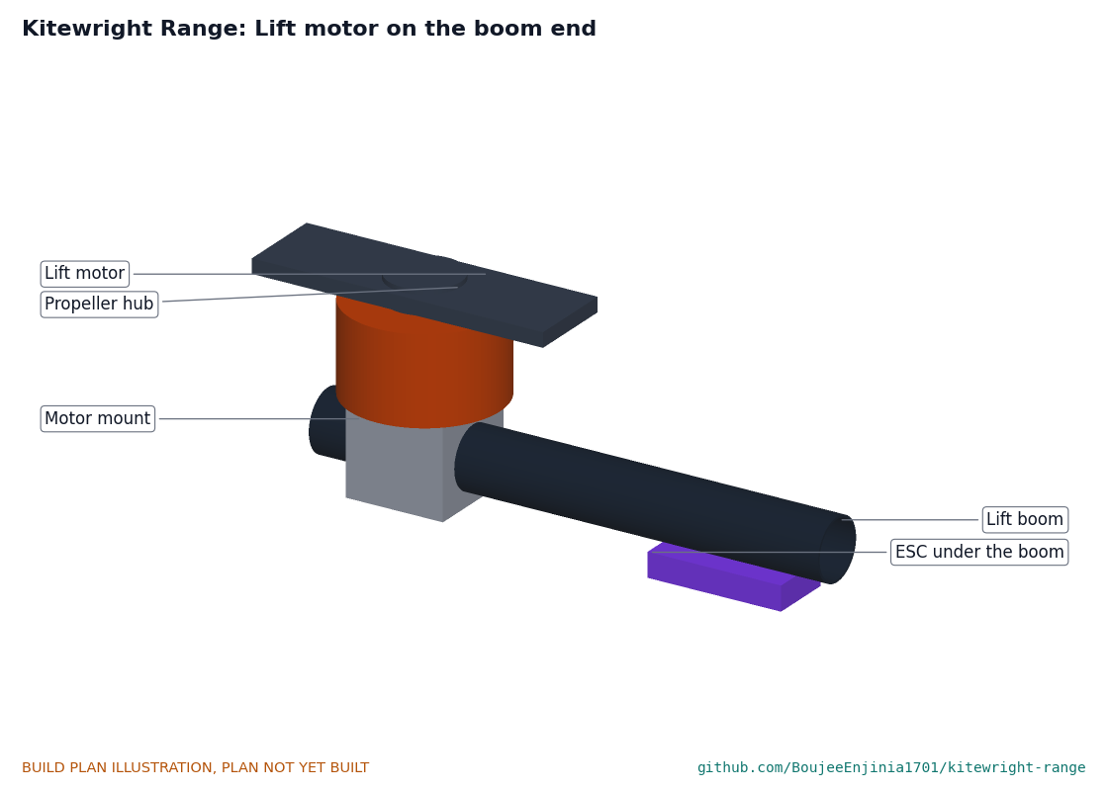
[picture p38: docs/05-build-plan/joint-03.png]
Figure 14. Lift motor joint


*Figure 14. Lift motor on its tube clamp mount at the boom end, with the ESC strapped under the boom.*

**Check before moving on.** With the boom in the pylon, the motor marks are the same distance ahead of and behind the pylon centre within 2 mm.

### 3.9 Landing legs (make 4)

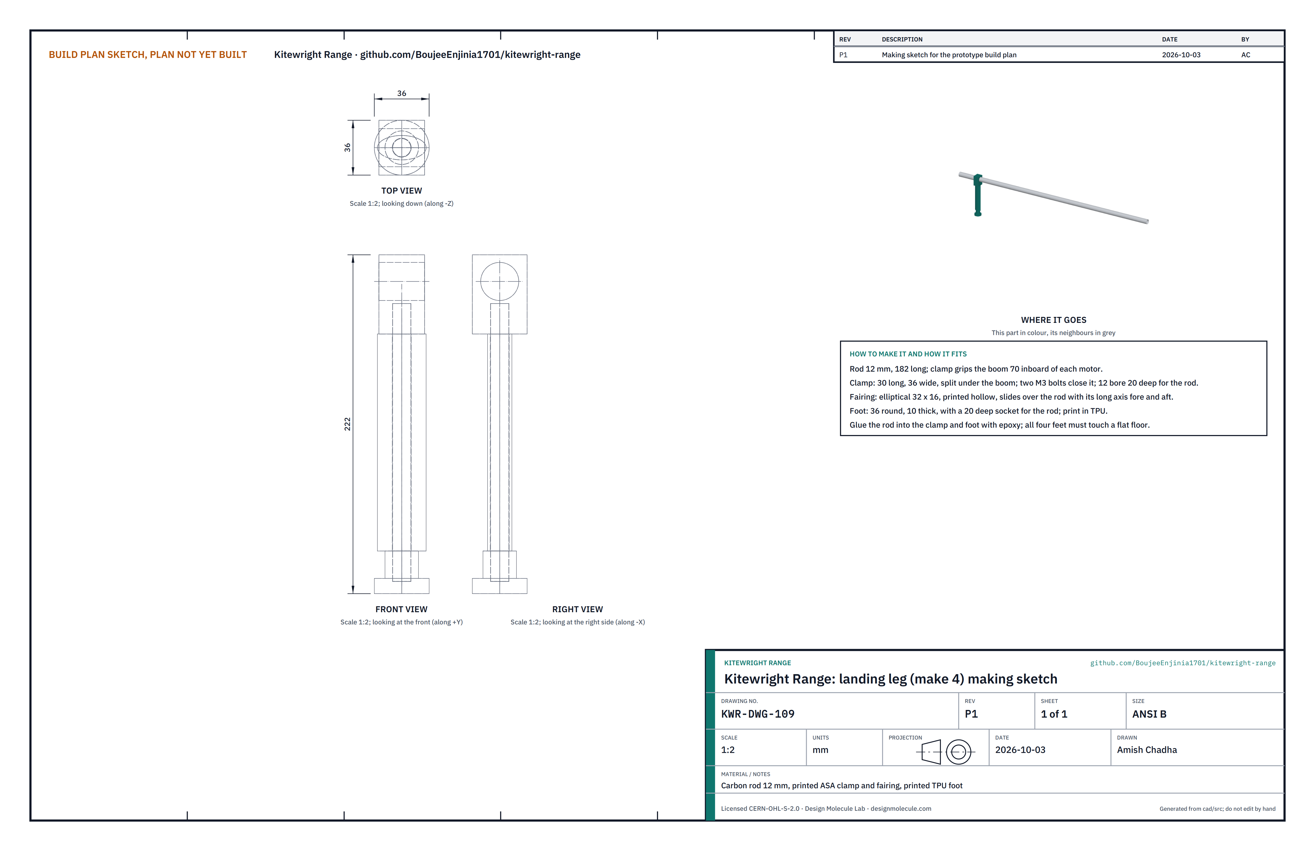
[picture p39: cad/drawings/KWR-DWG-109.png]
Figure 15. Landing leg making sketch


*Figure 15. Landing leg making sketch (KWR-DWG-109).*

**What it is and what it is made from.** A 12 mm carbon rod in a printed elliptical fairing 32 x 16 mm, with a printed ASA clamp on the boom and a printed TPU foot 36 mm across.

**How to make it.**

1. Cut the rod to 182 mm.
2. Print the clamp (split under the boom, two M3 bolts, 12 mm socket 20 mm deep), the hollow fairing and the TPU foot (20 mm socket).
3. Glue the rod into the clamp and foot with epoxy, with the fairing between them, its long axis fore and aft.

**How it fits the parts next to it.** The clamp closes round the boom 70 mm inboard of each motor (Figure 16).

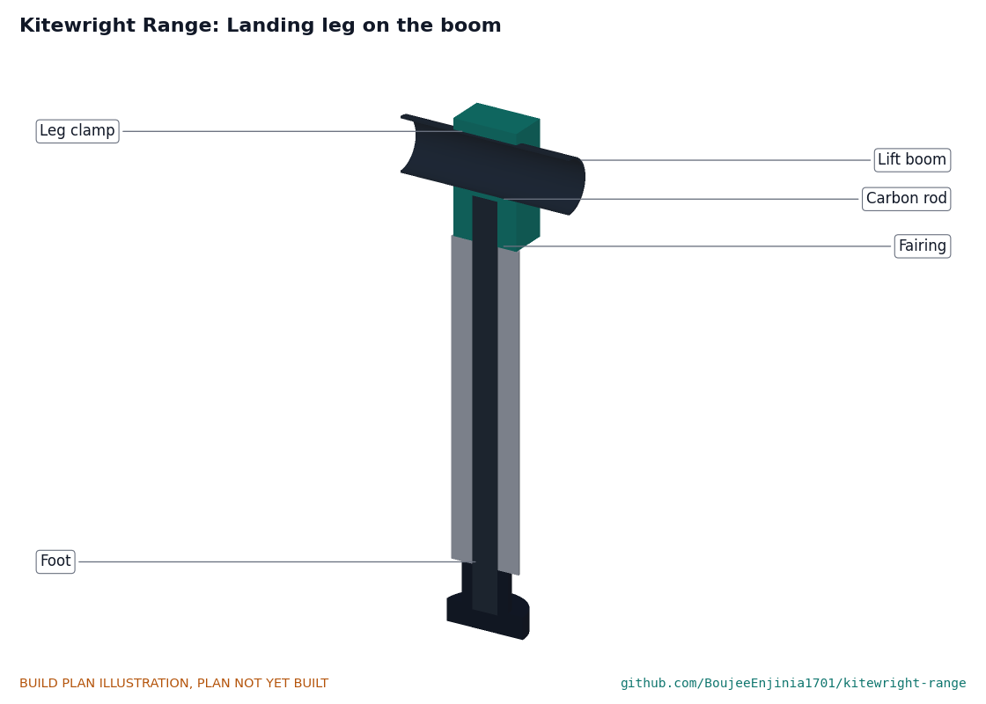
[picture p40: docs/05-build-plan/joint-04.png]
Figure 16. Landing leg joint


*Figure 16. Landing leg clamp on the boom, rod inside its fairing, foot at the bottom; cut along the boom.*

**Check before moving on.** All four feet touch a flat floor at once; the aircraft does not rock.

### 3.10 Tail boom

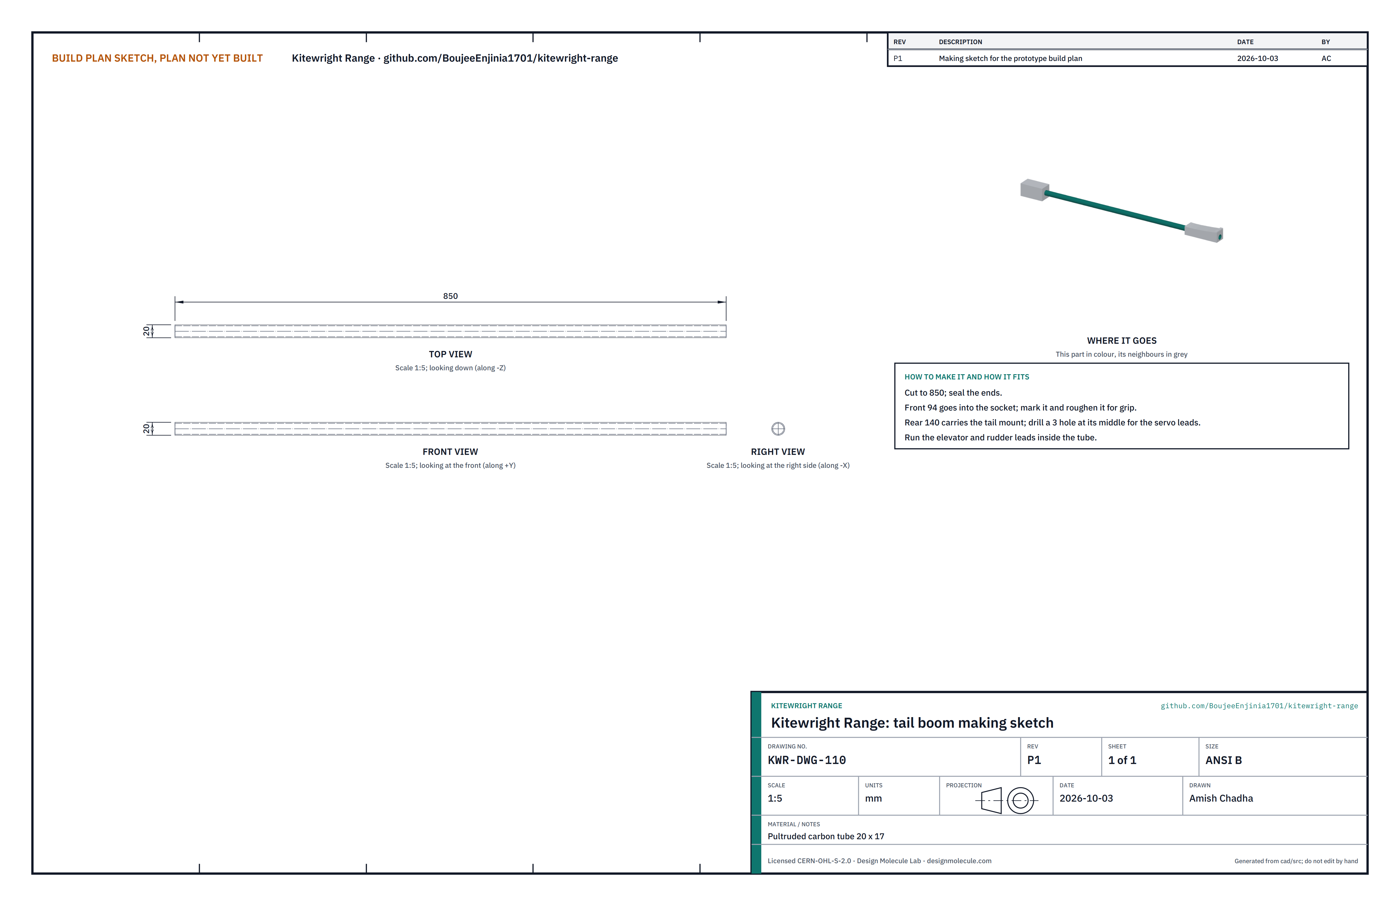
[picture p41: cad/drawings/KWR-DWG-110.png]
Figure 17. Tail boom making sketch


*Figure 17. Tail boom making sketch (KWR-DWG-110).*

**What it is and what it is made from.** Pultruded carbon tube 20 mm outside, 17 mm inside, 850 mm long.

**How to make it.** Cut to length and seal the ends. Roughen the front 94 mm for the socket. Drill a 3 mm hole 70 mm from the back end for the servo leads, which run inside the tube.

**How it fits the parts next to it.** The front goes through the rear wall into the socket (Figure 8); the back carries the tail mount.

**Check before moving on.** The tube is straight: rolled on a flat table, it does not wobble.

### 3.11 Tail mount

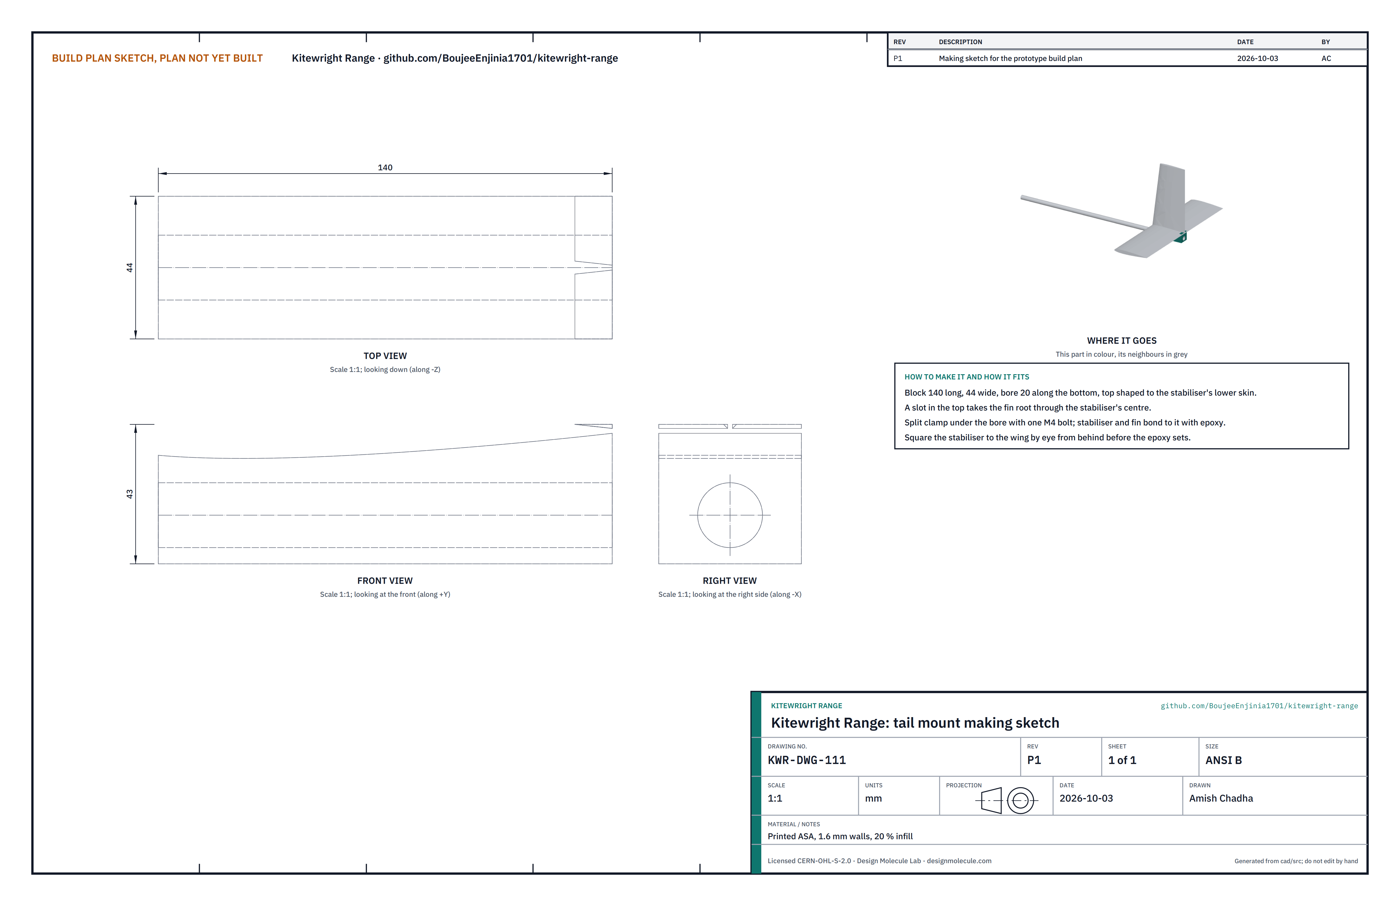
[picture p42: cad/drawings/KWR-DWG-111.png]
Figure 18. Tail mount making sketch


*Figure 18. Tail mount making sketch (KWR-DWG-111).*

**What it is and what it is made from.** A printed ASA block 140 mm long and 44 mm wide with a 20 mm bore along its bottom; its top is shaped to the stabiliser's lower skin, with a slot for the fin root.

**How to make it.** Print on its side, 1.6 mm walls, 20 % infill. Saw a slit under the bore and drill for one M4 clamp bolt.

**How it fits the parts next to it.** It clamps the end of the tail boom; the stabiliser and fin bond to it with epoxy (Figure 19).

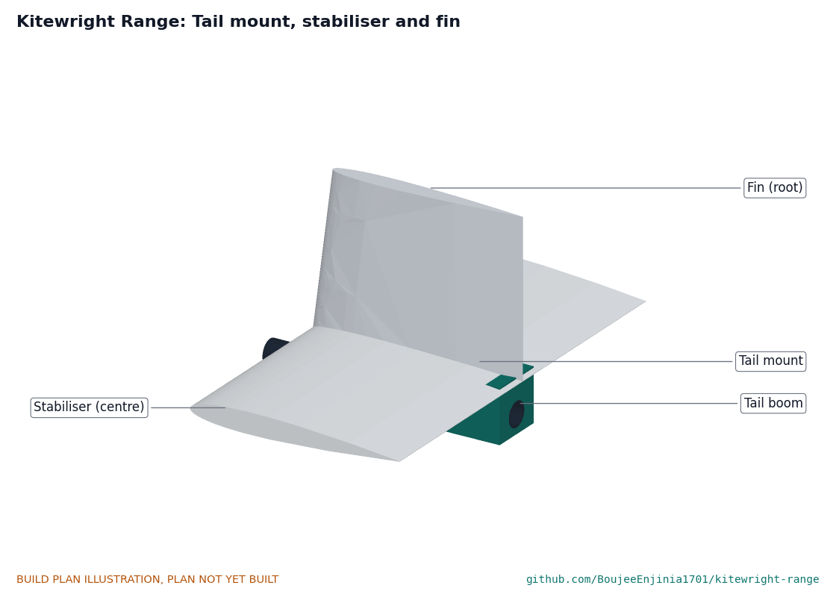
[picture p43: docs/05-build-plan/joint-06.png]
Figure 19. Tail mount joint


*Figure 19. Stabiliser and fin bonded to the tail mount on the end of the tail boom.*

**Check before moving on.** Seen from behind with the fuselage level, the mount's top is level.

### 3.12 Horizontal stabiliser with elevator

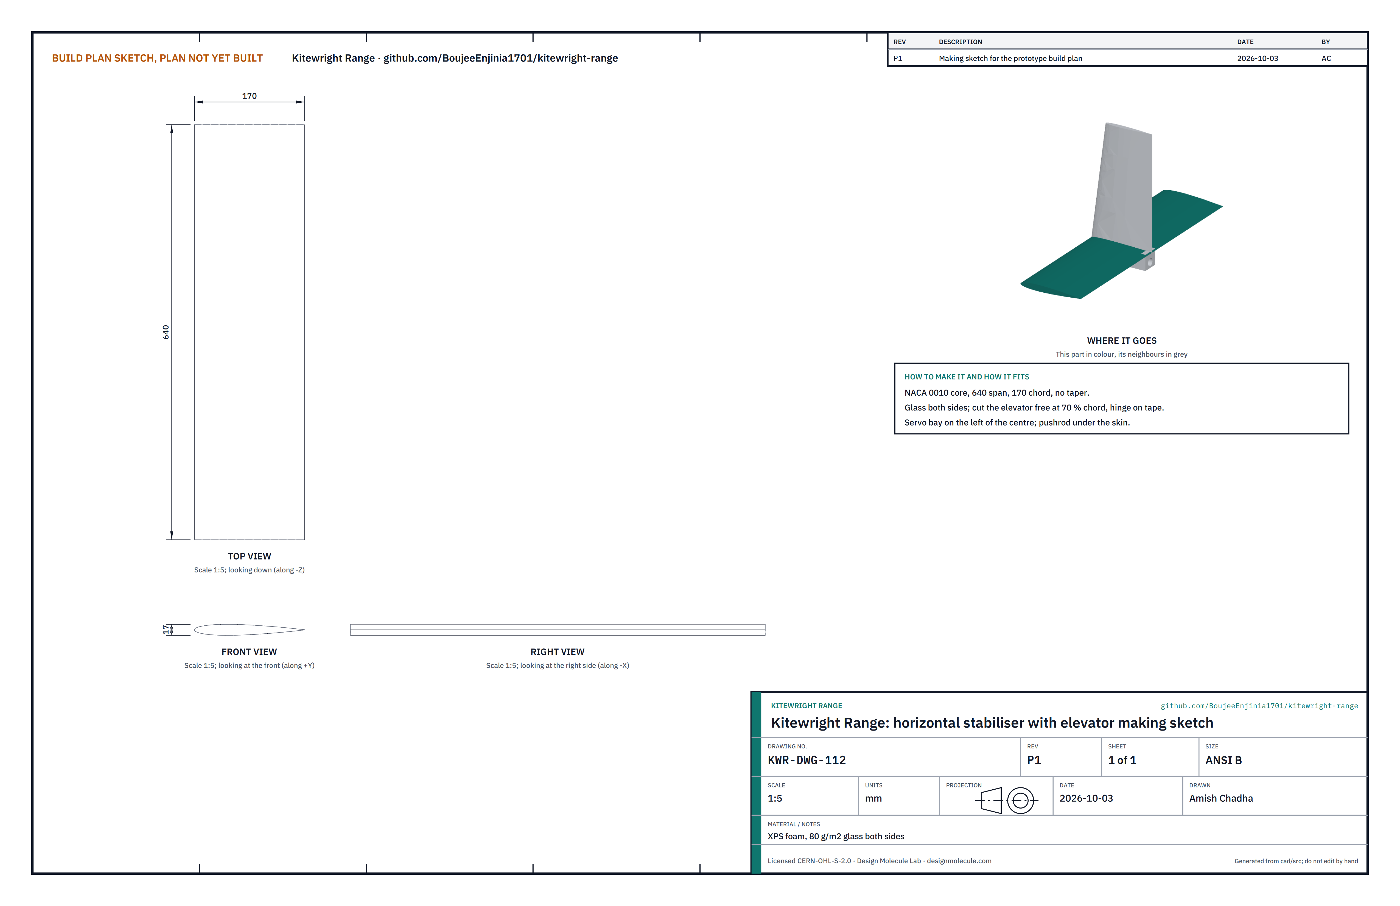
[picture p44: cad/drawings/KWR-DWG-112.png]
Figure 20. Stabiliser making sketch


*Figure 20. Stabiliser making sketch (KWR-DWG-112).*

**What it is and what it is made from.** A NACA 0010 foam core 640 x 170 mm, glass both sides, with an elevator.

**How to make it.** Hot-wire cut the core, cut the servo bay left of centre, glass both sides, cut the elevator free at 70 % chord and hinge it on tape.

**How it fits the parts next to it.** It bonds onto the tail mount, centred, square to the tail boom.

**Check before moving on.** Tip to tip it is level with the wing when viewed from behind.

### 3.13 Fin with rudder

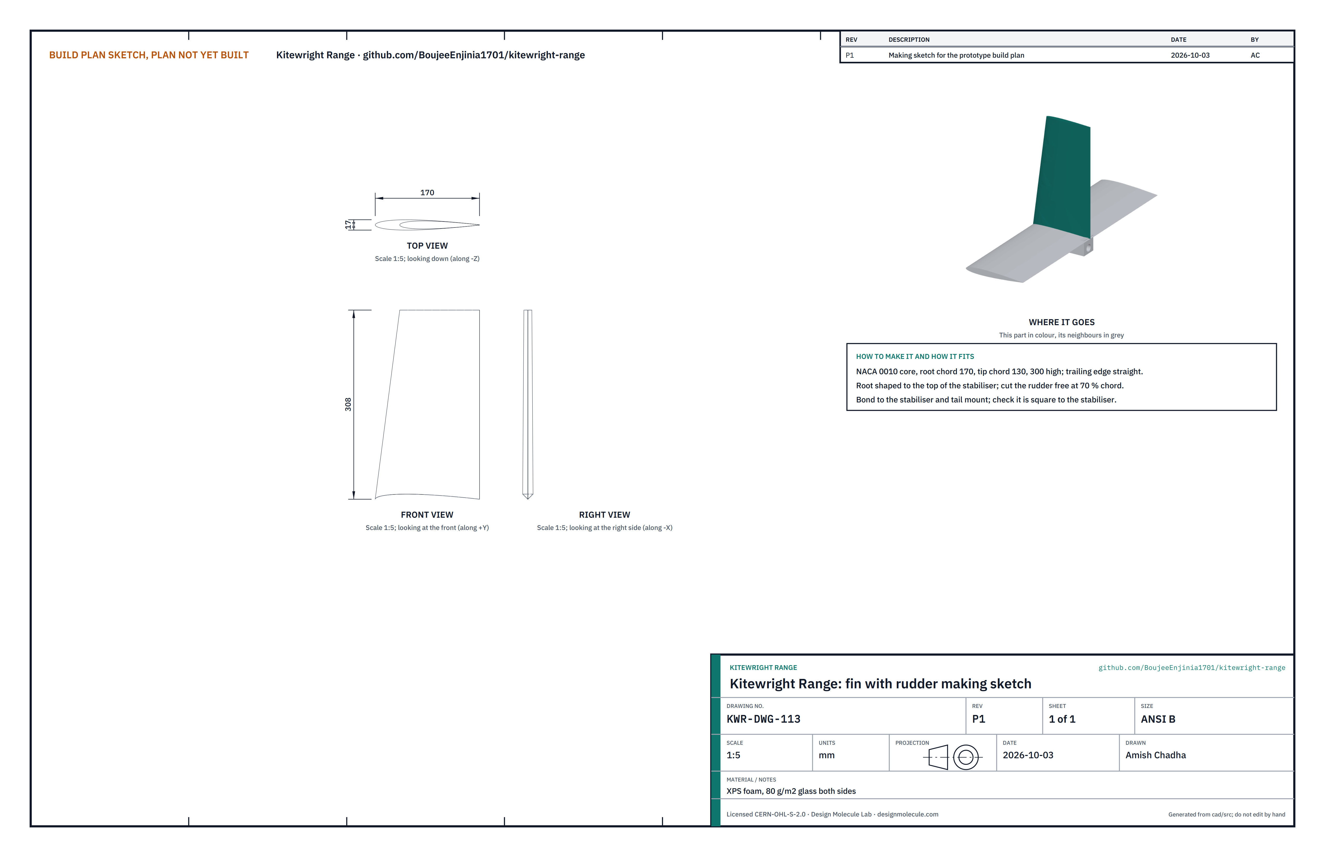
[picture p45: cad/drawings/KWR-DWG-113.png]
Figure 21. Fin making sketch


*Figure 21. Fin making sketch (KWR-DWG-113).*

**What it is and what it is made from.** A NACA 0010 foam core 300 mm high, 170 mm chord at the root and 130 mm at the tip, glass both sides, with a rudder.

**How to make it.** Hot-wire cut the core with its root shaped to the stabiliser top, glass it, cut the rudder free at 70 % chord and hinge it on tape.

**How it fits the parts next to it.** It bonds through the slot onto the stabiliser and the tail mount (Figure 19).

**Check before moving on.** It is square to the stabiliser, checked with a set square.

### 3.14 Bought components

| Component | What to buy | What to do to it |
| --- | --- | --- |
| Wing spars and joiner | Pultruded carbon tube 22 x 20 mm; roll-wrapped carbon tube 20 x 16 mm, 640 mm | Cut the spars to 1,160 mm; check the joiner slides into the spars |
| Wing bolts, pylon bolts | M5 x 40 nylon cap screws; M5 x 90 stainless cap screws with 15 mm washers | None |
| Lift motor mounts | Aluminium mounts that clamp a 25 mm tube, top plate at least 64 mm across | Drill the top plate to the motor's bolt pattern |
| Lift ESCs | 60 A, 6S, open firmware, rated to -20 °C | Extend the leads to the boom root plug |
| Lift motors and propellers | 5215-class, about 285 g, 6S, at least 7.0 kgf with a 22 x 7 in propeller; 22 x 7 in carbon, two of each hand | Balance every propeller |
| Cruise motor, ESC and propeller | 4120-class, 400 KV with a 60 A ESC; 14 x 10 in folding blades on a 36 mm spinner | None |
| Servos | Metal-gear digital, 20 mm class, rated to -20 °C | Fit in the servo bays with pushrods |
| Heated pitot | 6 mm probe with heater and airspeed sensor | Glue the tube into the left wing hole |
| Kitewright Core with its rail and pins | To the Kitewright Core design (KWC-BLD-001), 0.99 kg | None; its GNSS receiver and antennas move to the hatch on extension cables |
| ColdCell packs | Two 6S3P Li-ion packs of 5.0 Ah 21700 cells with AS150 leads, 138 x 75 x 82 mm | None |
| Core power leads | 8 AWG silicone wire, red and black, 2 m; four AS150 connector halves | Cut four lead pairs about 100 mm long; solder a plug to each, inputs and outputs of opposite gender; label them PACK 1, PACK 2, FRAME A and FRAME B |
| Harness | 10 and 12 AWG silicone wire, AS150 on every pack and bus lead, XT60 on the boom root plugs, arming plug; three 300 mm SMA extension leads | Make to the Core wiring diagram |

## 4. Putting it together

### Step 1: tail boom socket into the fuselage

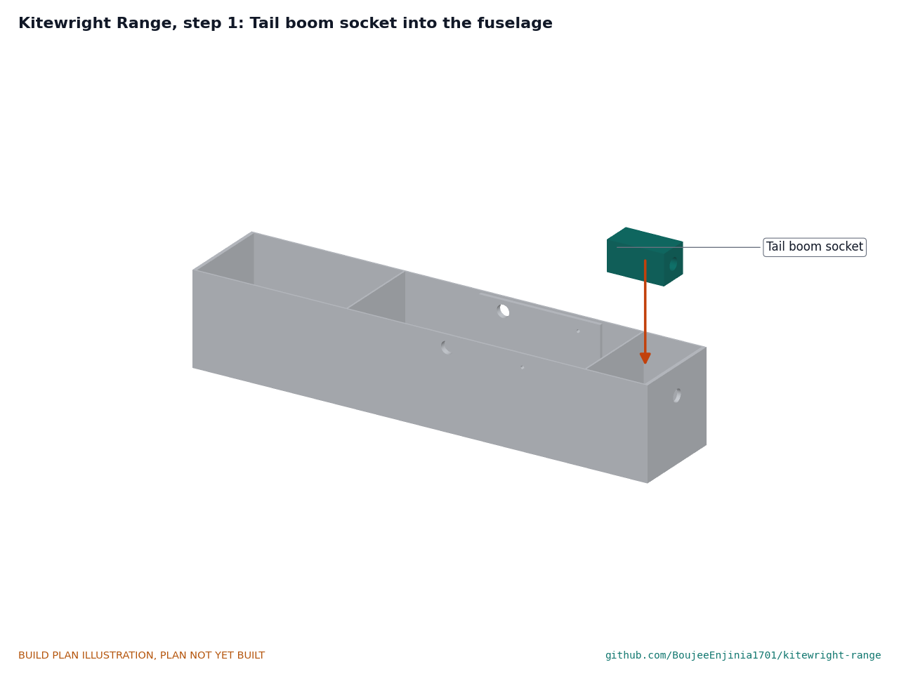
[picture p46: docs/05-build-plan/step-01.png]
Step 1


*Figure 22. Step 1.* Glue the socket to the rear wall and floor with its bore on the rear wall hole. Hold the bore in line with a rod until the epoxy sets.

### Step 2: nose cone onto the firewall

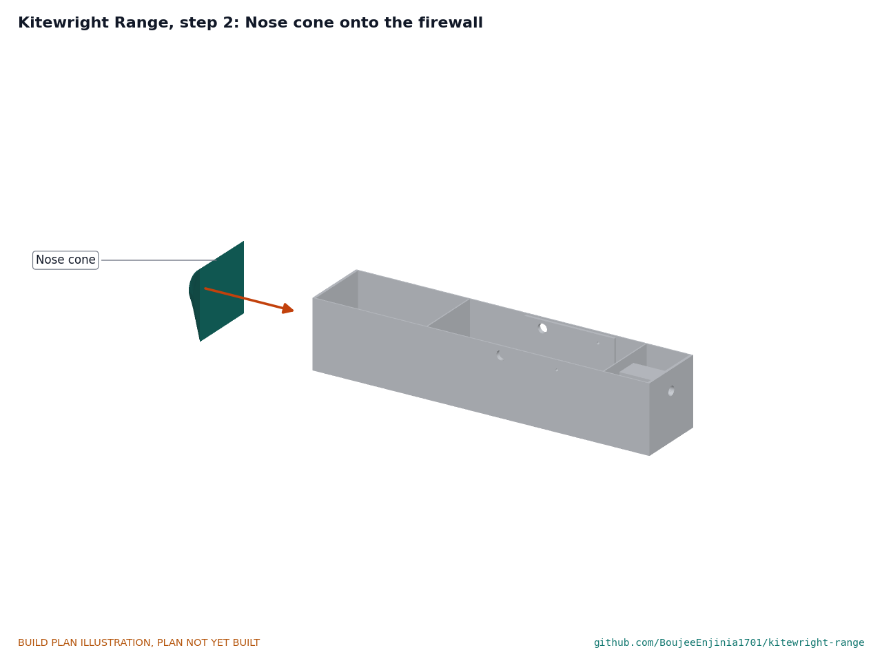
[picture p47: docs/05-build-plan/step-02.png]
Step 2


*Figure 23. Step 2.* Epoxy and four M4 bolts through the firewall.

### Step 3: cruise motor and folding propeller

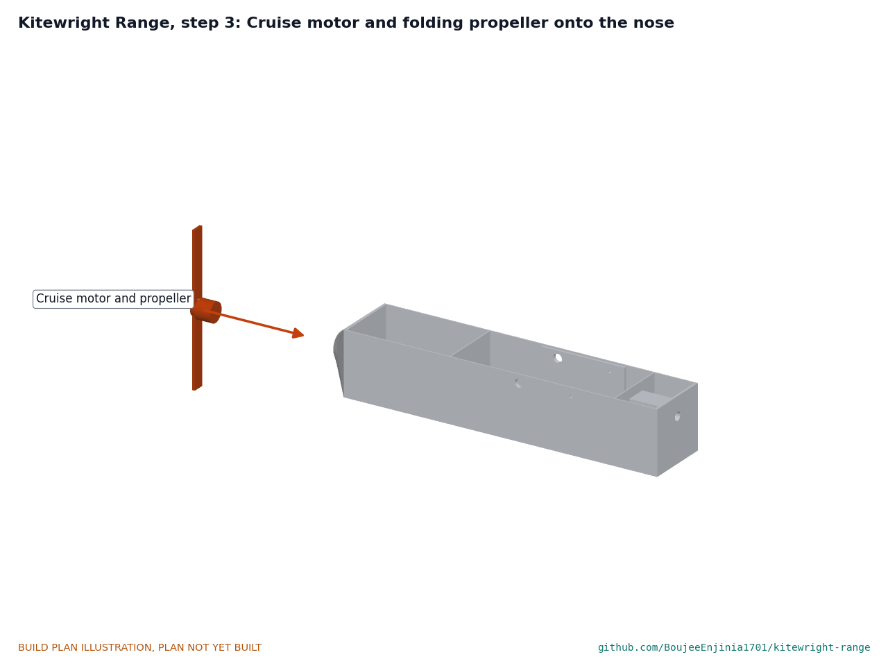
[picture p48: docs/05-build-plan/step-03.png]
Step 3


*Figure 24. Step 3.* Four M3 bolts with threadlock into the nose cone inserts. Fit the spinner and yoke; leave the blades off until the propeller safety stop.

### Step 4: Core deck doubler onto the floor

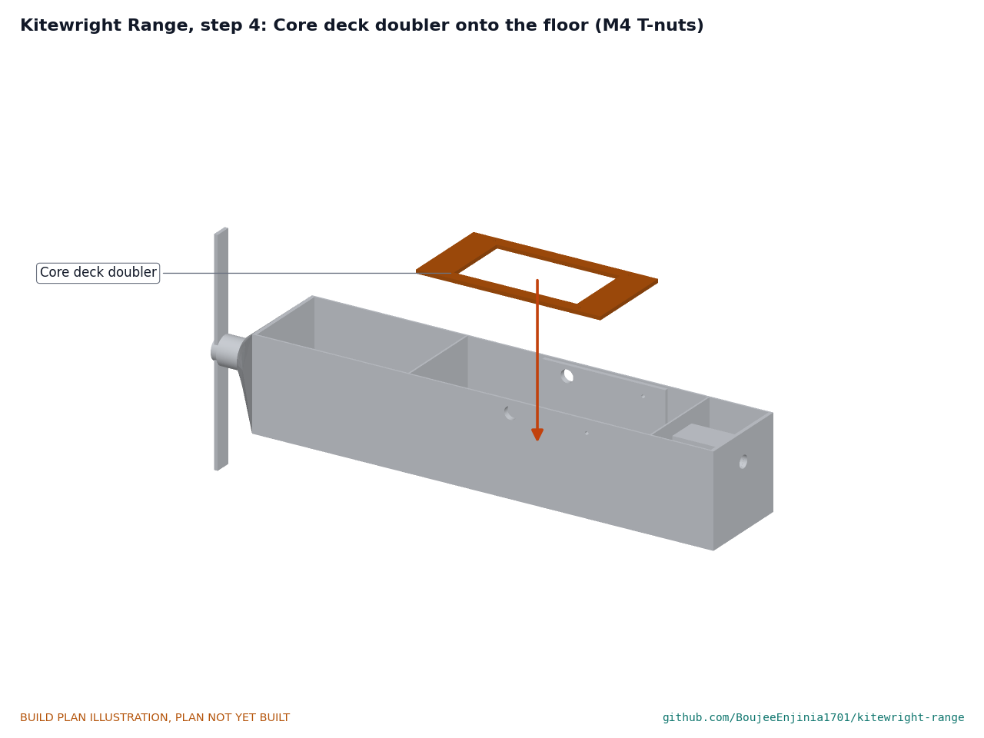
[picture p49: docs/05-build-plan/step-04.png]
Step 4


*Figure 25. Step 4.* Glue the doubler on the floor with its opening over the floor's opening and its four holes over the floor's; press the M4 T-nuts home from above.

### Step 5: Kitewright Core under the floor

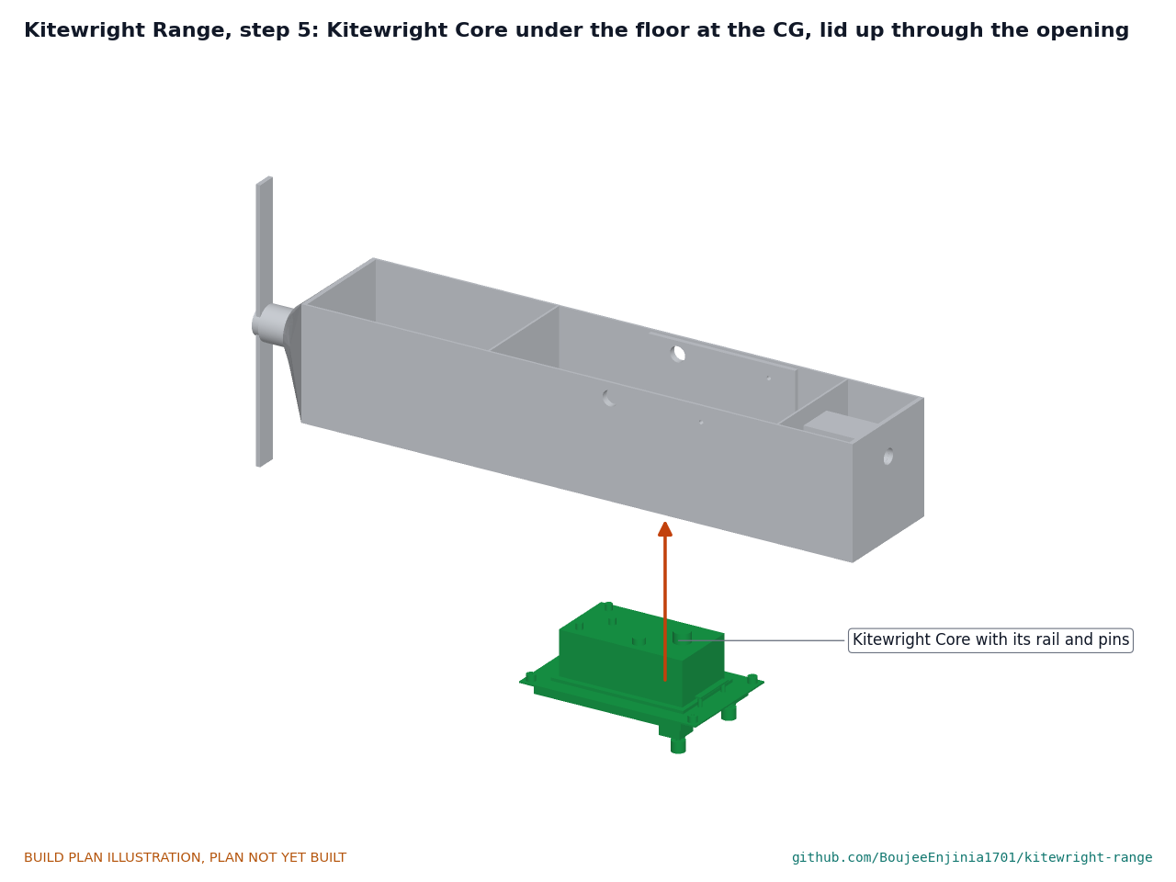
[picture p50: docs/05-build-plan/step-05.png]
Step 5


*Figure 26. Step 5.* Before the Core goes on, solder the four Core power leads to the Core's pads and pass them out through its grommets: PACK 1 and PACK 2 to the two battery bays, FRAME A and FRAME B to the harness for the lift and cruise ESCs. Check polarity at each plug with a meter. Then, from below, push the Core's lid up through the floor opening with its rail pointing aft, until its four corner spacers meet the floor, and fit four M4 screws into the T-nuts. Run the harness to both battery bays, the wing root plugs and the tail.

### Step 6: tail boom into the socket

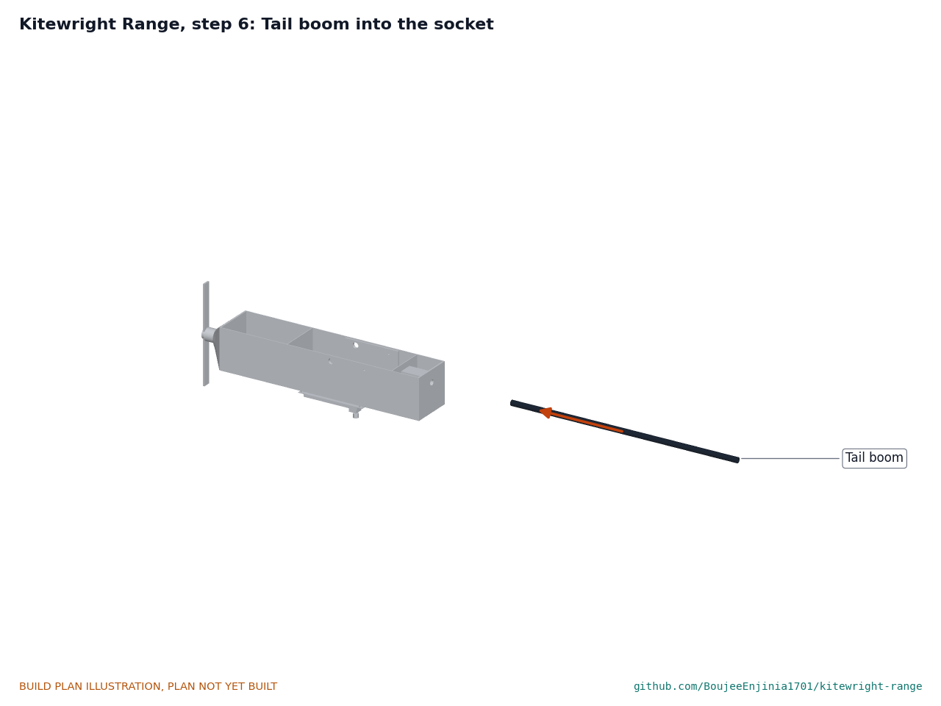
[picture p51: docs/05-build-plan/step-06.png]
Step 6


*Figure 27. Step 6.* Slide the boom through the rear wall into the socket and tighten the clamp bolt, with the servo-lead hole facing up.

### Step 7: tail mount, stabiliser and fin

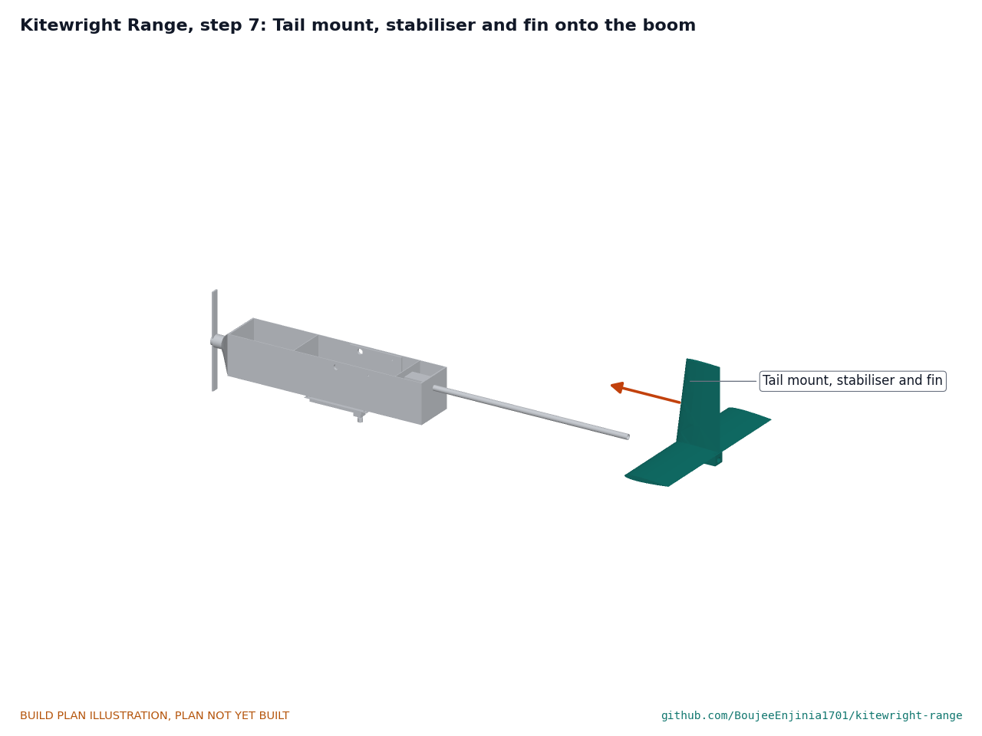
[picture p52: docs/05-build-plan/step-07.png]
Step 7


*Figure 28. Step 7.* Clamp the tail mount on the boom end and bond the stabiliser and fin to it. Hold point: from behind, the stabiliser is parallel to the fuselage floor and the fin is upright.

### Step 8: boom pylon onto each wing panel

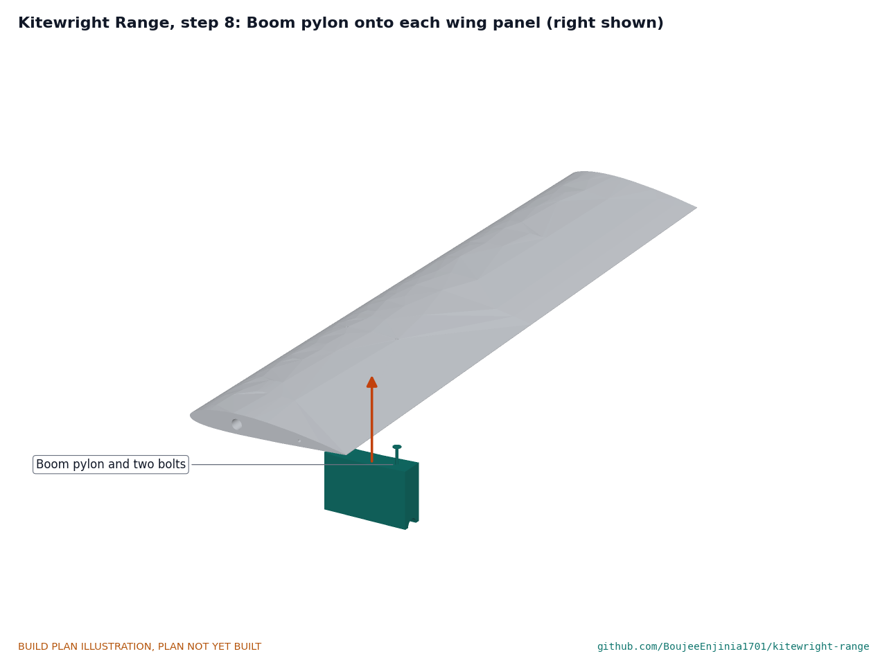
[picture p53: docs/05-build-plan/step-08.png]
Step 8


*Figure 29. Step 8.* Bond each pylon to its hardpoints, then fit the two M5 bolts from the top with washers. Let the epoxy cure for 24 hours.

### Step 9: joiner, then the wing panels

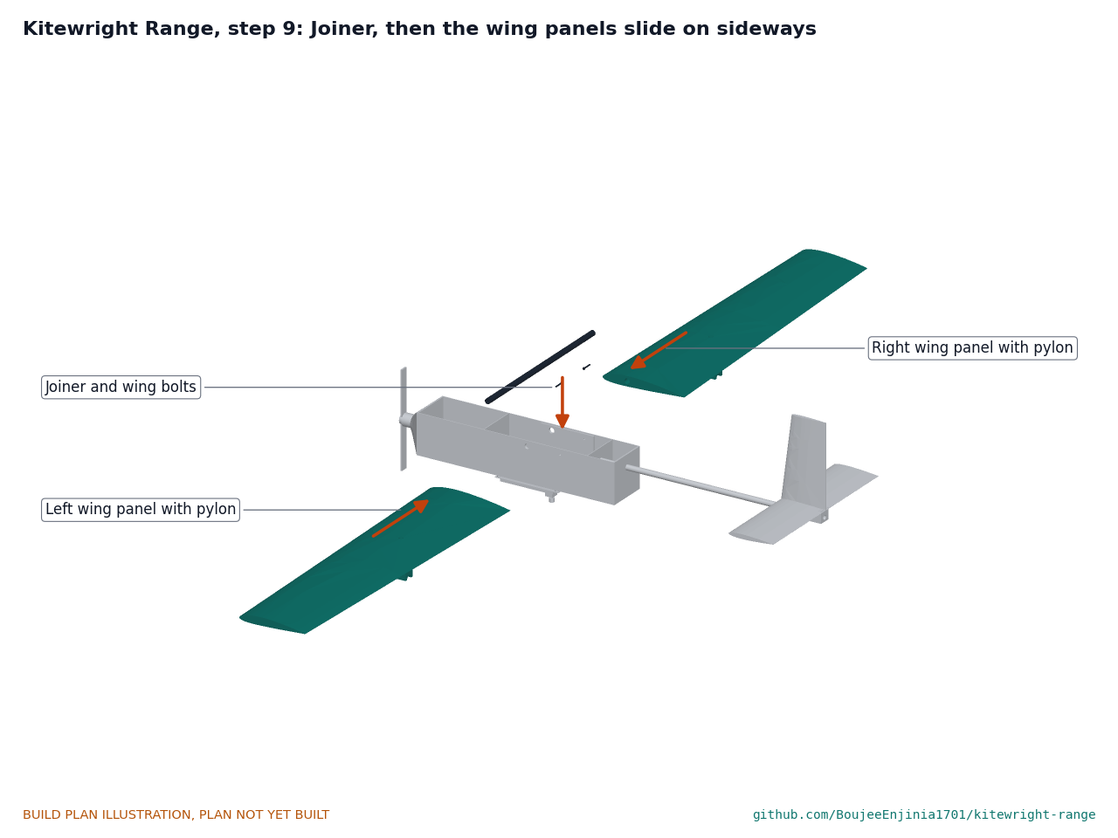
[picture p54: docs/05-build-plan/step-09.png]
Step 9


*Figure 30. Step 9.* Slide the joiner through the fuselage, push each panel onto it until the root rib meets the fuselage side, and fit the nylon wing bolts from inside. Connect the boom root plugs.

### Step 10: lift booms into the pylons

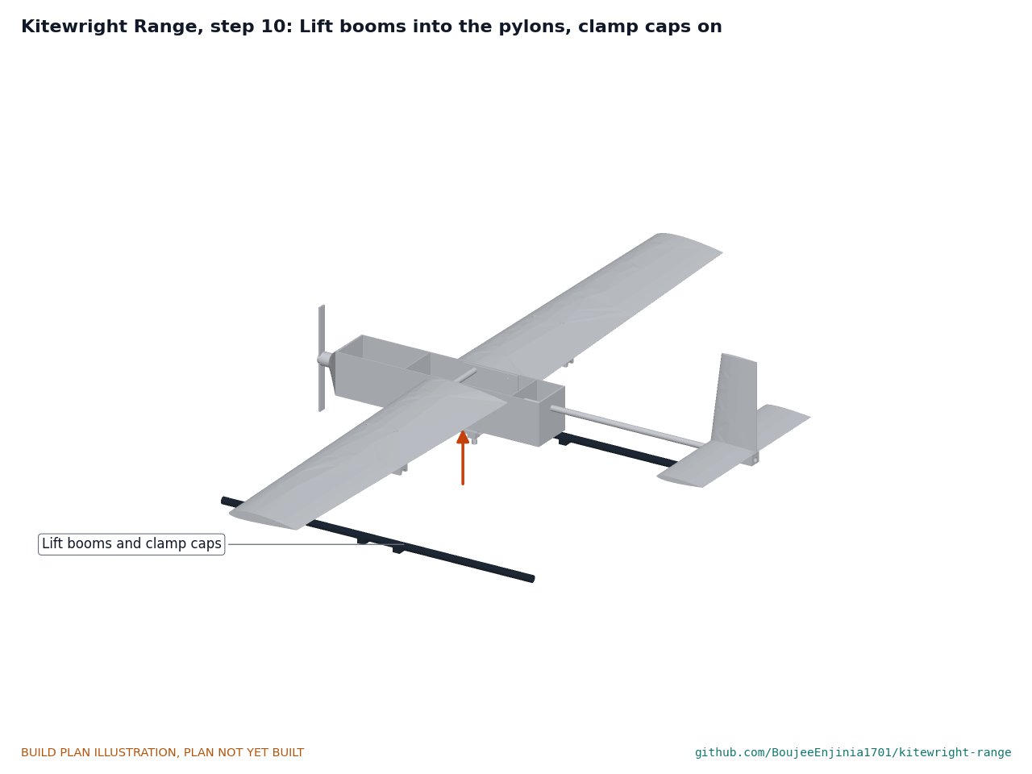
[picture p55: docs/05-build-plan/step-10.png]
Step 10


*Figure 31. Step 10.* Lay each boom in its saddle with its centre mark on the pylon centre and fit the two clamp caps.

### Step 11: motor mounts, ESCs and lift motors

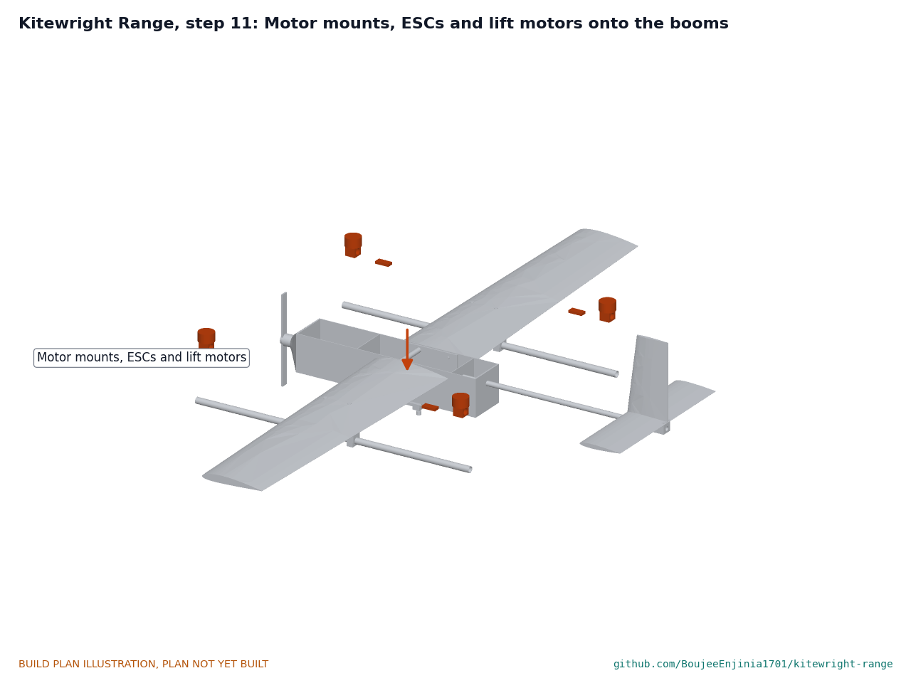
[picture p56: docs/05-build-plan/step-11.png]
Step 11


*Figure 32. Step 11.* Clamp the motor mounts at the marks with the top plates level, bolt on the motors (front left and rear right turn one way, the other two the other way, to the PX4 quadplane layout), strap the ESCs under the boom and run the wires through the 6 mm holes into the boom.

### Step 12: landing legs

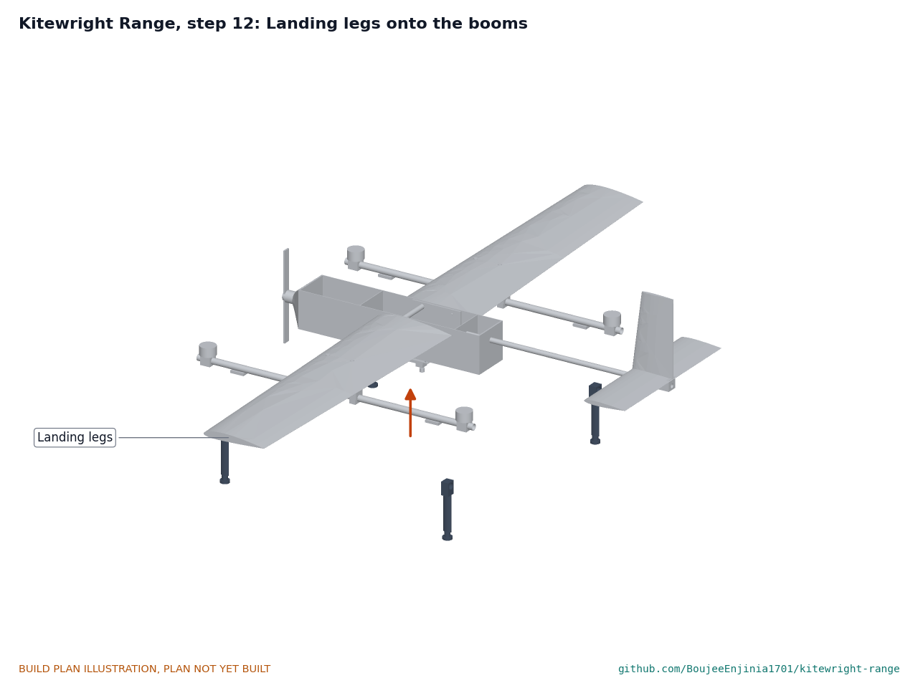
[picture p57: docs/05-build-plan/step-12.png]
Step 12


*Figure 33. Step 12.* Clamp the legs 70 mm inboard of each motor with the fairings fore and aft.

### Step 13: ColdCell packs into the bays

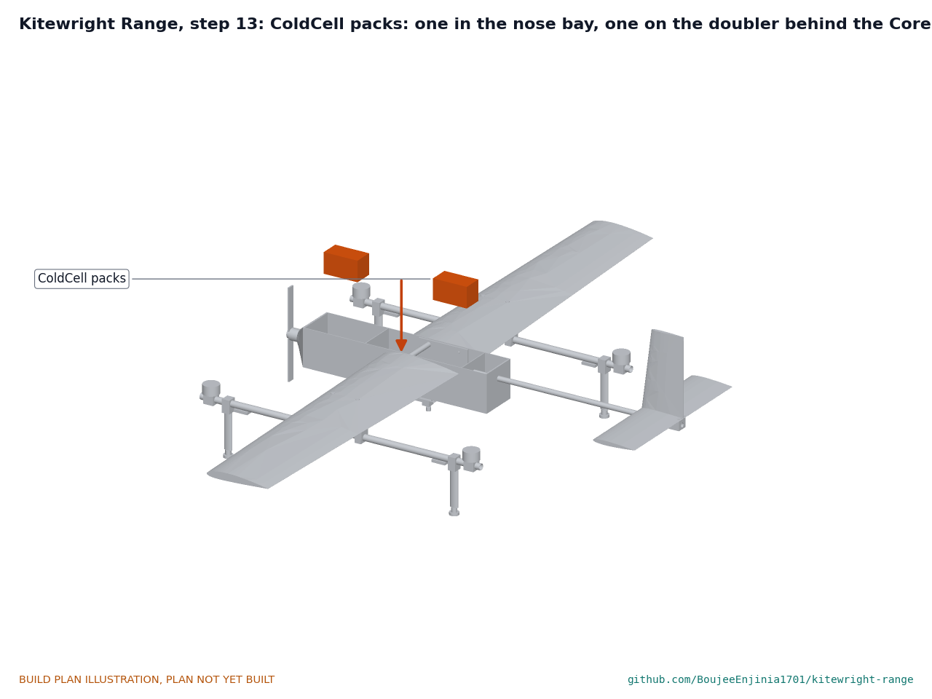
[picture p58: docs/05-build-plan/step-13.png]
Step 13


*Figure 34. Step 13.* One pack in the nose bay, on the floor, and one on the doubler behind the Core's lid, each held by a hook-and-loop strap. Plug them into PACK 1 and PACK 2 (AS150). Leave the arming plug out.

### Step 14: hatch and GNSS mast

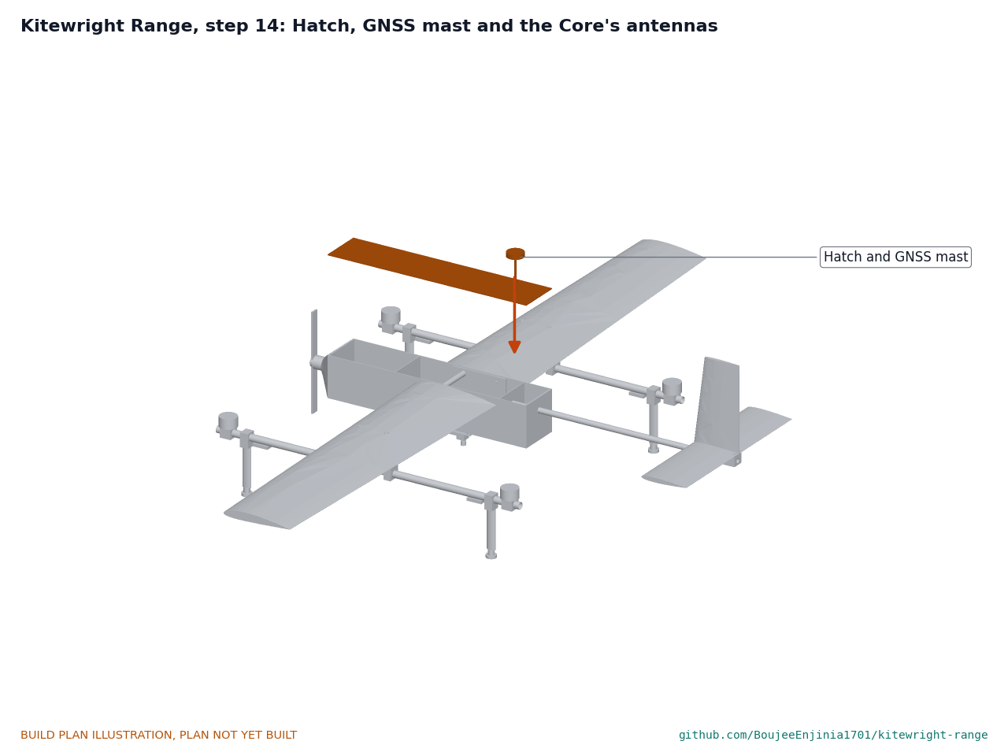
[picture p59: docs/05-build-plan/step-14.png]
Step 14


*Figure 35. Step 14.* Screw the three SMA extension leads onto the Core's lid bulkheads and push the antennas up through the hatch holes; slide the hatch tongue under the firewall lip, fit the thumb screw and plug the GNSS mast, with the Core's GNSS receiver on top, through the hatch.

### Step 15: lift propellers and pitot probe

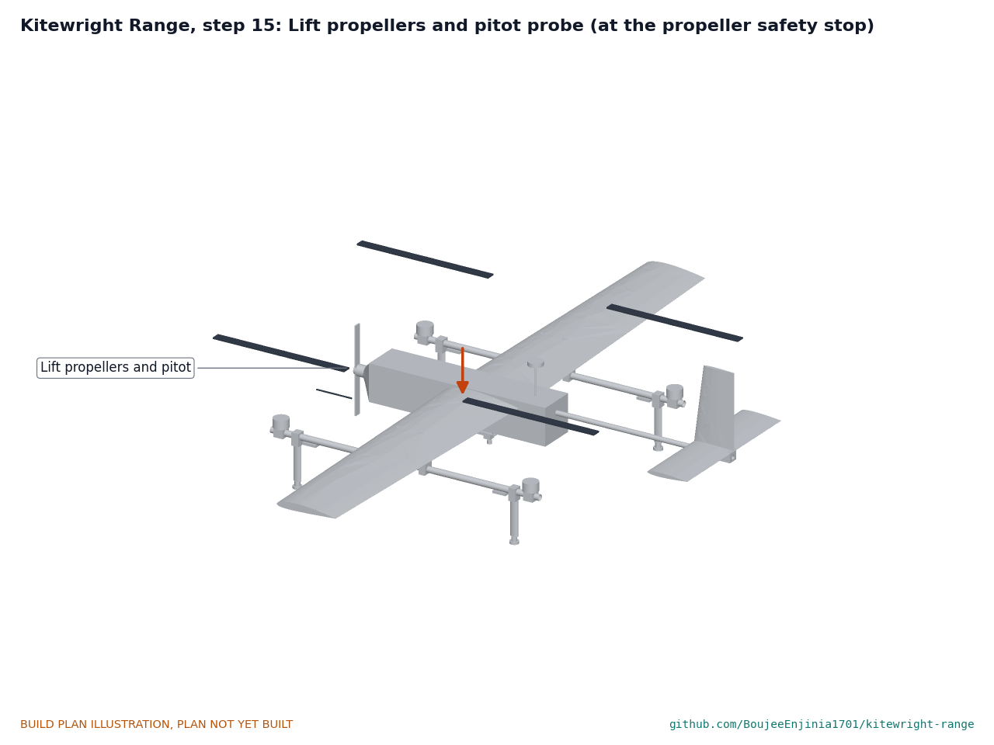
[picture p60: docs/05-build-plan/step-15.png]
Step 15


*Figure 36. Step 15.* Only at the propeller safety stop (section 6). Fit each propeller to the hand of its motor and the cruise blades to the yoke; glue the pitot tube into the left wing.

### Step 16: payload onto the mount

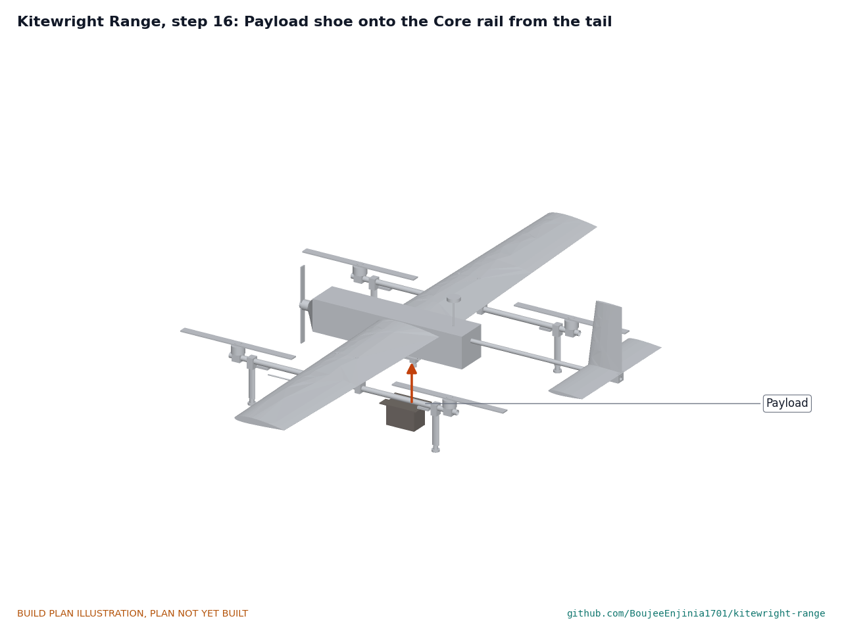
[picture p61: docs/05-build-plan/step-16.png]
Step 16


*Figure 37. Step 16.* From the tail end, slide the payload's shoe onto the Core's rail lips until it meets the front stops; both locking pins drop into the shoe. Plug the Core's DS-014 pigtail into the payload.

## 5. First checks

| Check | Requirement | How | Pass when |
| --- | --- | --- | --- |
| Weigh and balance with and without the 1 kg payload | R4, R7 | Scales under the feet; balance point on the wing | Balance point within 26 % to 31 % of the mean chord both ways; mass recorded |
| Design-around geometry | R9 | Measure from a straightedge across the wing top to each propeller | Every rotor disc at least 70 mm below the wing-top plane |
| Pack and case | R8 | Pack the aircraft into its two cases | Every part fits; each case under the target mass |
| Control surface throws | R6 | Radio check with the arming plug out | Each surface moves the right way with no binding |
| Cold soak of servos and ESCs | R5 | Chamber soak at -20 °C, then function check, propellers off | Every servo and ESC works |
| Motor run, propellers off | R1 | Arm with the aircraft tied down and propellers off | Each motor turns the right way for its position |
| Tied hover thrust | R1 | AltiRig data at 5,000 m density, then a tied hover at the build site | Measured thrust margin recorded for the as-built mass |

These checks are listed here; a TRL 4 test report records them.

## 6. Safety stops

> **Safety:** Work stops at each point below until what is listed is true.

1. **Before the first power-up:** the arming plug is out, no propeller is fitted, a fire extinguisher for lithium fires and a fire-resistant box are at hand, and the packs have been charged between 0 and 45 °C pack temperature.
2. **Before any motor runs:** the aircraft is tied down to a bench, propellers off, the lockable arming switch works, and the PX4 failsafes (loss of link, low battery, geofence) are set and checked on the ground station.
3. **Propeller safety stop, before any propeller goes on:** every person is outside a 15 m keep-out zone during arming, the aircraft is tied to ground anchors, the motor directions are confirmed, and every propeller is balanced and checked for cracks.
4. **Before the first free hover:** ten logged tied hovers with no fault, the wing spar proof-loaded (TRL 4), the measured thrust margin known, and the site cleared with the landowner and local aviation rules.
5. **After any hard landing or crash:** remove the arming plug, move the packs outdoors to a safe area, and treat them as damaged until checked.

## 7. Tools, skills and workspace

- Hot-wire foam cutter with root and tip templates; vacuum bagging or peel ply for glassing; epoxy, scales and mixing gear.
- Fine-tooth saw, abrasive disc for carbon tube, drill press or guide, 20.5 mm and 5.5 mm drills, heat-set insert tip.
- 3D printer that prints ASA and TPU, with an enclosure.
- Soldering for 10 AWG wire and AS150 connectors, and a 100 W iron or better for the 8 AWG Core power leads and AS150 plugs (hold the hot wire with pliers); a multimeter.
- A 2.6 m flat bench, a well-ventilated room for epoxy and carbon dust (wear a dust mask), and an outdoor area for powered tests.
- Skills: model aircraft building, multirotor wiring, PX4 setup with a ground station.

## 8. Where the numbers come from

- Model and constructability checks: `cad/src/model.py`; STEP and STL in `cad/step/` and `cad/stl/`.
- General arrangement: `cad/drawings/KWR-DWG-001`; making sketches `cad/drawings/KWR-DWG-101` to `KWR-DWG-113`.
- Pictures: `cad/src/build_plan_media.py`, written to `docs/05-build-plan/`.
- Calculations: `docs/04-calcs/01-sizing.md` (KWR-CAL-001) and `docs/04-calcs/sizing.py`.
- Bill of materials: `bom/bom.csv`.
- Decisions: `docs/decisions/0001-trl2-review-decisions.md`, `docs/decisions/0002-design-for-construction.md`, `docs/decisions/0003-requirement-decisions.md` and `docs/06-design-decisions.md`.

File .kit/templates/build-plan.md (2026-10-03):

---
doc_id: PRJ-BLD-001
title: Project prototype build plan
project: Project name
doc_type: Build plan
version: "0.1"
status: Draft
date: YYYY-MM-DD
author: Amish Chadha
license: CERN-OHL-S-2.0
revisions:
  - version: "0.1"
    date: YYYY-MM-DD
    author: Amish Chadha
    change: First build plan; design made constructable
---

# Project prototype build plan

**Plan, not yet built.** How to build the first proof-of-concept prototype, component by component. Building and testing to it is TRL 4 work. Decisions still to be made are kept in the design decisions register (`docs/06-design-decisions.md`), not here.

## 1. What you are building

Every component, pulled apart and numbered in build order

One short paragraph: what the prototype is, how many components, which are made and which are bought, and the main ways they are made.

## 2. What changed to make it buildable

| Component | The concept had | The buildable design has | Why |
| --- | --- | --- | --- |

## 3. Making the components

### 3.1 Component name

Making sketch

**What it is and what it is made from.**

**How to make it.**

1. Mark out ...
2. Cut ...

**How it fits the parts next to it.**

Close-up of the joint

**Check before moving on.**

## 4. Putting it together

### Step 1: ...

Step 1

## 5. First checks

| Check | Requirement | How | Pass when |
| --- | --- | --- | --- |

## 6. Safety stops

## 7. Tools, skills and workspace

## 8. Where the numbers come from

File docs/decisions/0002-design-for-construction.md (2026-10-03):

---
doc_id: KWR-DDR-002
title: Kitewright Range design for construction
project: Kitewright Range
doc_type: Design decision record
version: "0.1"
status: Draft
date: '2026-10-03'
author: Amish Chadha
license: CERN-OHL-S-2.0
revisions:
- version: "0.1"
  date: '2026-10-03'
  author: Amish Chadha
  change: Changes that make the concept buildable, with the reason for each; decided under Amish's 2026-10-03 pre-approval
---

# 0002: Design for construction

- **Date:** 2026-10-03
- **Status:** accepted under Amish's pre-approval. Amish, 2026-10-03: "start with the first 14 repos from the list of 29 projects. I pre-approve the batch runs along with any recommendations you come up with. I also accept any cost overruns or variations from the assumed scope cost." and "Proceed with the remaining 15 scaffolds".

## Context

The scaffold precis (KWR-PRC-001 v0.1) described the quadplane in words: a wing in removable halves, a fuselage pod, two booms under the wing carrying the lift motors and the tail, and a pusher or tractor cruise motor. It did not say how the booms hold on, where the motors sit relative to the centre of gravity and the propeller discs, how the wing comes apart, where the packs go or what the aircraft stands on. Writing the build plan (STANDARDS section 18, Amish 2026-09-30: "fix the design assumptions to match and be physically feasible") settled each of these in `cad/src/model.py`.

The changes keep what the concept does: an all-electric quadplane with one fixed wing, four fixed lift motors with their discs clear of the wing-top plane, one electric cruise motor, the Kitewright Core and its payload mount, and ColdCell packs. Nothing here changes the pitch, the patent design-arounds or the safety case. The model now runs constructability checks with build123d (`python cad/src/model.py`): 72 solids in 48 parts, no two overlapping, none floating, rotor discs at least 70 mm below the wing-top plane, the lift and cruise discs apart, and every part shorter than the 1.3 m case. All pass.

## Decision

Table 1. Changes made to the model, the BOM and the calculations

| # | The concept had | The constructable design has | Why |
| --- | --- | --- | --- |
| C1 | Tail carried on the lift booms | A conventional tail on a 20 mm carbon tail boom from the back of the fuselage | Booms that also reach the tail would be about 1.6 m long and miss the 1.3 m case; the rear rotor wash stays off the tail |
| C2 | Booms "below the wing", no fixing shown | A printed pylon under each wing at 470 mm out, through-bolted with two M5 bolts to plywood hardpoints, the boom held in its saddle by two clamp caps | Gives a bolted, removable boom joint and puts the rotor discs 81 mm below the wing-top plane (design-around R9) |
| C3 | Boom spacing not set | Booms 470 mm either side of the centre line | Keeps the front lift discs 38 mm clear of the cruise propeller disc |
| C4 | Motor positions not set | Lift motors 506 mm ahead of and behind the centre of gravity on each boom | Hover thrust acts through the centre of gravity; the front discs clear the leading edge by 171 mm and the rear discs the trailing edge by 44 mm |
| C5 | Pusher or tractor cruise motor | Tractor at the nose on a printed nose cone, 14 in folding propeller | Nothing behind the fuselage for a pusher to clear; the blades fold back when stopped for landing |
| C6 | Removable wing halves | Two panels on a 20 x 16 mm carbon joiner through the fuselage sides, 6 mm plywood doublers, one nylon M5 wing bolt into each root rib; spar straight at 30 % chord | A straight spar can be a stock tube; the joiner and bolt are the usual field-proven fixing |
| C7 | Fuselage pod, contents not placed | Lite-ply box with a firewall, two bulkheads and a rear wall; Core avionics in the front bay; one ColdCell pack either side of the joiner | Each pack lifts straight out through the hatch with the wing fitted; the packs and payload sit on the centre of gravity |
| C8 | No landing gear | Four landing legs on the booms, 70 mm inboard of the motors: carbon rods in printed fairings with rubber feet | The aircraft stands level on rough ground with 83 mm under the payload; fairings cut leg drag by about four fifths |
| C9 | Wiring not shown | A 10 mm conduit in each wing from the pylon to the root rib, root plugs for each boom, ESCs strapped under the booms | The boom power runs inside the wing and disconnects with it |
| C10 | Payload mount position not set | Core payload mount on four M4 inserts in the floor, centred on the centre of gravity | Fitting or removing the payload does not move the balance (R4) |
| C11 | Tail joint not shown | A printed socket glued inside the rear wall with a split clamp; a printed tail mount that the stabiliser and fin bond to | Tail comes off for transport with one bolt |
| C12 | No hatch | Lite-ply hatch with a front tongue, a rear thumb screw, the GNSS mast and the lockable arming switch | Access to the packs and avionics without tools |
| C13 | Pitot position not set | Heated pitot set into the left wing leading edge, 800 mm out | Clean air outside the propeller wash |

## Consequences

- Take-off mass rose to 10.58 kg once every made part was weighed from the model (KWR-CAL-001 v0.2). R2 and R7 are not met and R1 and R3 are at risk; they are open decisions for Amish, not changed here.
- STEP and STL, the general arrangement (KWR-DWG-001 Rev P2), the concept media and the build plan pictures are regenerated from the changed model.
- The BOM gained the pylons, clamp caps, pylon bolts, landing legs, tail socket, tail mount, wing bolts, transport cases and arming switch.

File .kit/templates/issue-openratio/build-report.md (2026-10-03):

---
name: Build report
about: Tell us what happened when you built, printed or tested part of this design
title: "Build report: "
labels: build-report
---

This is a research and educational prototype, not a medical device. It is a TRL 3 concept and is not released for fabrication. If you build any part of it, you do so at your own risk. Reports help everyone.

**What you built** (part, sub-assembly or test)

**Materials, tools and settings**

**What worked**

**What did not work, with photos or measurements if you have them**

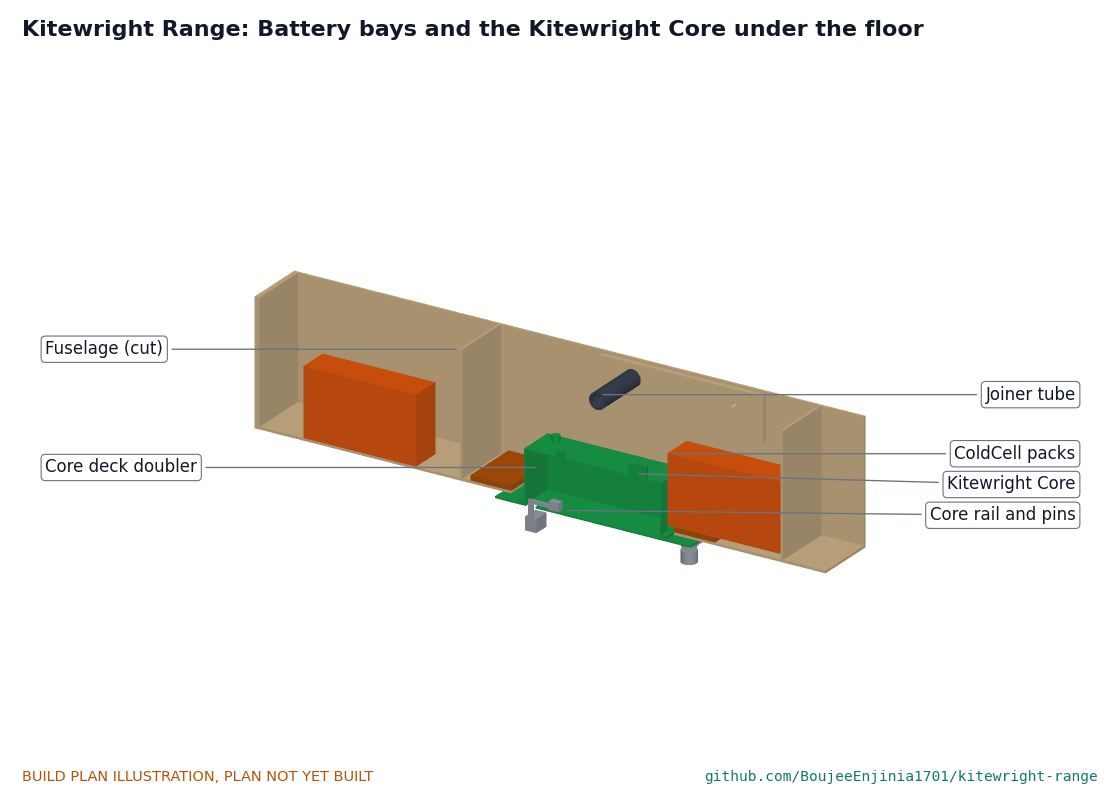
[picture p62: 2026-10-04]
docs/05-build-plan/joint-08.png

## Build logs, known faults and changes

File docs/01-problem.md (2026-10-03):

---
doc_id: KWR-PRB-001
title: Kitewright Range problem statement
project: Kitewright Range
doc_type: Problem statement
version: "0.2"
status: Draft
date: '2026-10-03'
author: Amish Chadha
license: CERN-OHL-S-2.0
revisions:
- version: "0.1"
  date: '2026-09-30'
  author: Amish Chadha
  change: Initial scaffold
- version: "0.2"
  date: '2026-10-03'
  author: Amish Chadha
  change: Open questions answered by KWR-DDR-001; budget stated as a value-engineering target; co-design candidate named
---

# Kitewright Range problem statement

High-mountain hazards sit where people cannot easily go and where small drones struggle to fly. Lakes and glaciers above 4,500 m need regular, wide-area surveys, but the season is short, the air is thin and cold, and the tools that work are closed and costly.

## The problem

Glacial lakes are growing fast: their number rose 53% and their volume 48% between 1990 and 2020 ([Taylor et al., 2023](https://www.nature.com/articles/s41467-023-36033-x)). In India, work on 189 high-risk lakes is limited to four summer months because of elevation and weather ([ThePrint, 2024](https://theprint.in/india/govt-approves-rs-150-crore-for-glacial-lake-outburst-flood-risk-mitigation-programme-for-4-states/2232525/)). The South Lhonak lake in Sikkim, at 5,200 m, burst on 4 October 2023 after scientists had warned of it for years ([Nature India, 2023](https://www.nature.com/articles/d44151-023-00152-7)), and no early warning system was working there when it failed ([Mongabay India, 2023](http://india.mongabay.com/2023/10/no-early-warning-system-and-insufficient-dam-safety-turned-sikkim-flood-deadly/)).

Multirotors can fly high, as DJI showed with delivery tests between 5,300 m and 6,000 m on Everest in April 2024 ([DJI, 2024](https://www.dji.com/media-center/announcements/dji-completes-world-first-drone-delivery-tests-on-mount-everest-en)), but hovering is expensive in thin air and limits range. Fixed-wing VTOL drones solve the range problem; ArduPilot and PX4 already support the quadplane layout in open firmware ([ArduPilot](https://ardupilot.org/plane/docs/quadplane-overview.html)). What is missing is an open, documented airframe tuned for 5,000 m and -20 C, built around a shared payload mount and a cold-rated battery, at a cost a regional agency can replace after a crash.

## Users and context

| User | Need | Context |
| --- | --- | --- |
| State disaster management authorities and their field teams | Repeatable lake and moraine surveys without a long trek to each lake | Himalayan lakes at 4,500 to 5,500 m, short summer season, remote launch sites |
| University glaciology and hydrology groups | An airframe they can inspect, modify and fly with their own sensors | Field campaigns on glaciers and snow basins; data for peer-reviewed work |
| Mountain NGOs and community disaster committees | A drone they can maintain locally and afford to replace | Villages below known hazardous lakes in India, Nepal and Pakistan |
| Mountain rescue organisations | A wide-area first sweep before a multirotor narrows a search | Valleys, glaciers and high passes; daylight, variable wind |

## Operating environment

- Launch and landing on rough, sloping ground at up to 5,000 m, from a clearing of about 10 m by 10 m (estimate).
- Air temperature -20 to +25 C (-4 to +77 F); air density down to about 0.74 kg/m3 at 5,000 m in the standard atmosphere ([Engineering ToolBox](https://www.engineeringtoolbox.com/standard-atmosphere-d_604.html)).
- Valley winds and gusts; snow, sleet and strong ultraviolet light.
- No mains power at the launch site; charging from a generator, vehicle or solar kit at base camp.
- Beyond cellular coverage; line-of-sight radio link to a ground station.

## Constraints

- Value-engineering target USD 5,000 for the airframe with its share of core avionics, excluding payloads (a hypothetical control target, not a spending limit).
- All-electric only. The hybrid generator pack is shelved and not part of this design.
- Single fixed wing, fixed (non-tilting) lift and cruise motors, lift rotor discs clear of the wing-top plane, per the preliminary patent screen.
- Uses the Kitewright Core autopilot, power bus and payload mount unchanged; no frame-specific payload interface.
- Open design: hardware under CERN-OHL-S-2.0, software under an open licence compatible with PX4 (BSD 3-Clause) or ArduPilot (GPLv3).
- Civilian use only; transportable in a vehicle and carried by two people on a trail (target).

## Out of scope

- Tail-sitter, tilt-rotor and tilt-wing layouts.
- Hybrid, fuel-cell or combustion power.
- Aviation certification (FAA Part 107, EASA, India DGCA Drone Rules 2021) at this TRL; to be addressed if prototypes progress.
- Beyond-visual-line-of-sight approvals and satellite links in the first version.
- Any weapon, targeting or military payload.

## Prior work

| Prior work | What it does | Gap for these users | Source |
| --- | --- | --- | --- |
| Quantum Systems Trinity Pro | Commercial fixed-wing eVTOL mapping drone: 90 min flight time, 5.75 kg take-off mass, 5,500 m service ceiling, -12 to 50 C | Closed and about USD 23,790; ceiling and cold limit sit at the edge of Himalayan lake survey needs | [link](https://quantum-systems.com/trinity-pro/) |
| ArduPilot QuadPlane | Open flight control code for fixed wing aircraft with separate VTOL motors, including tilt and tail-sitter variants | Firmware only; no open, documented airframe tuned for 5,000 m and -20 C | [link](https://ardupilot.org/plane/docs/quadplane-overview.html) |
| US9120560B1, vertical take-off and landing aircraft (Vertical Autonomy) | Fixed wing with head and tail booms and four VTOL rotors in a plane even with the wing top surfaces; anticipated expiry 2033 | A live patent that constrains boom and rotor placement; Kitewright Range places the rotor discs clear of that plane | [link](https://patents.google.com/patent/US9120560B1/en) |
| DJI FlyCart 30 Everest delivery tests | Unmodified heavy-lift multirotor flew between 5,300 m and 6,000 m at -15 to 5 C in April 2024 | A multirotor built for short hauls, not long surveys; closed platform | [link](https://www.dji.com/media-center/announcements/dji-completes-world-first-drone-delivery-tests-on-mount-everest-en) |

## Co-design

A state disaster management authority or a university glaciology group already running Himalayan lake surveys, because they know the launch sites, flight distances and data formats the frame must meet, and can host early flight trials under their own permissions.

## Open questions

The scaffold's open questions were answered on 2026-10-03 under Amish's pre-approval (KWR-DDR-001):

- Reference firmware: PX4 quadplane, matching the Kitewright Core (D1).
- Wing: 2.50 m span in two 1.18 m panels, aspect ratio 8.9, set by the 1.3 m transport case (D2).
- Propellers: one set of 20 in propellers for every altitude band (D3).
- LakeWatch: 1 kg on Range; the sampling winch belongs on Kitewright Lift (D4).
- Co-design: the Sikkim State Disaster Management Authority is the first candidate to approach, a university glaciology group the second; neither is agreed (D8).

Requirements the design does not yet meet are open decisions for Amish in `docs/06-design-decisions.md`.

> **Safety:** Kitewright Range is a 10.6 kg aircraft with four 20 in lift propellers, a folding cruise propeller and about 580 Wh of lithium-ion cells. Propeller strikes, lithium fire after a crash or a cold charge, and a crash in remote terrain after loss of link are the main hazards; the precis (KWR-PRC-001) and the build plan's safety stops (KWR-BLD-001) set out the controls.

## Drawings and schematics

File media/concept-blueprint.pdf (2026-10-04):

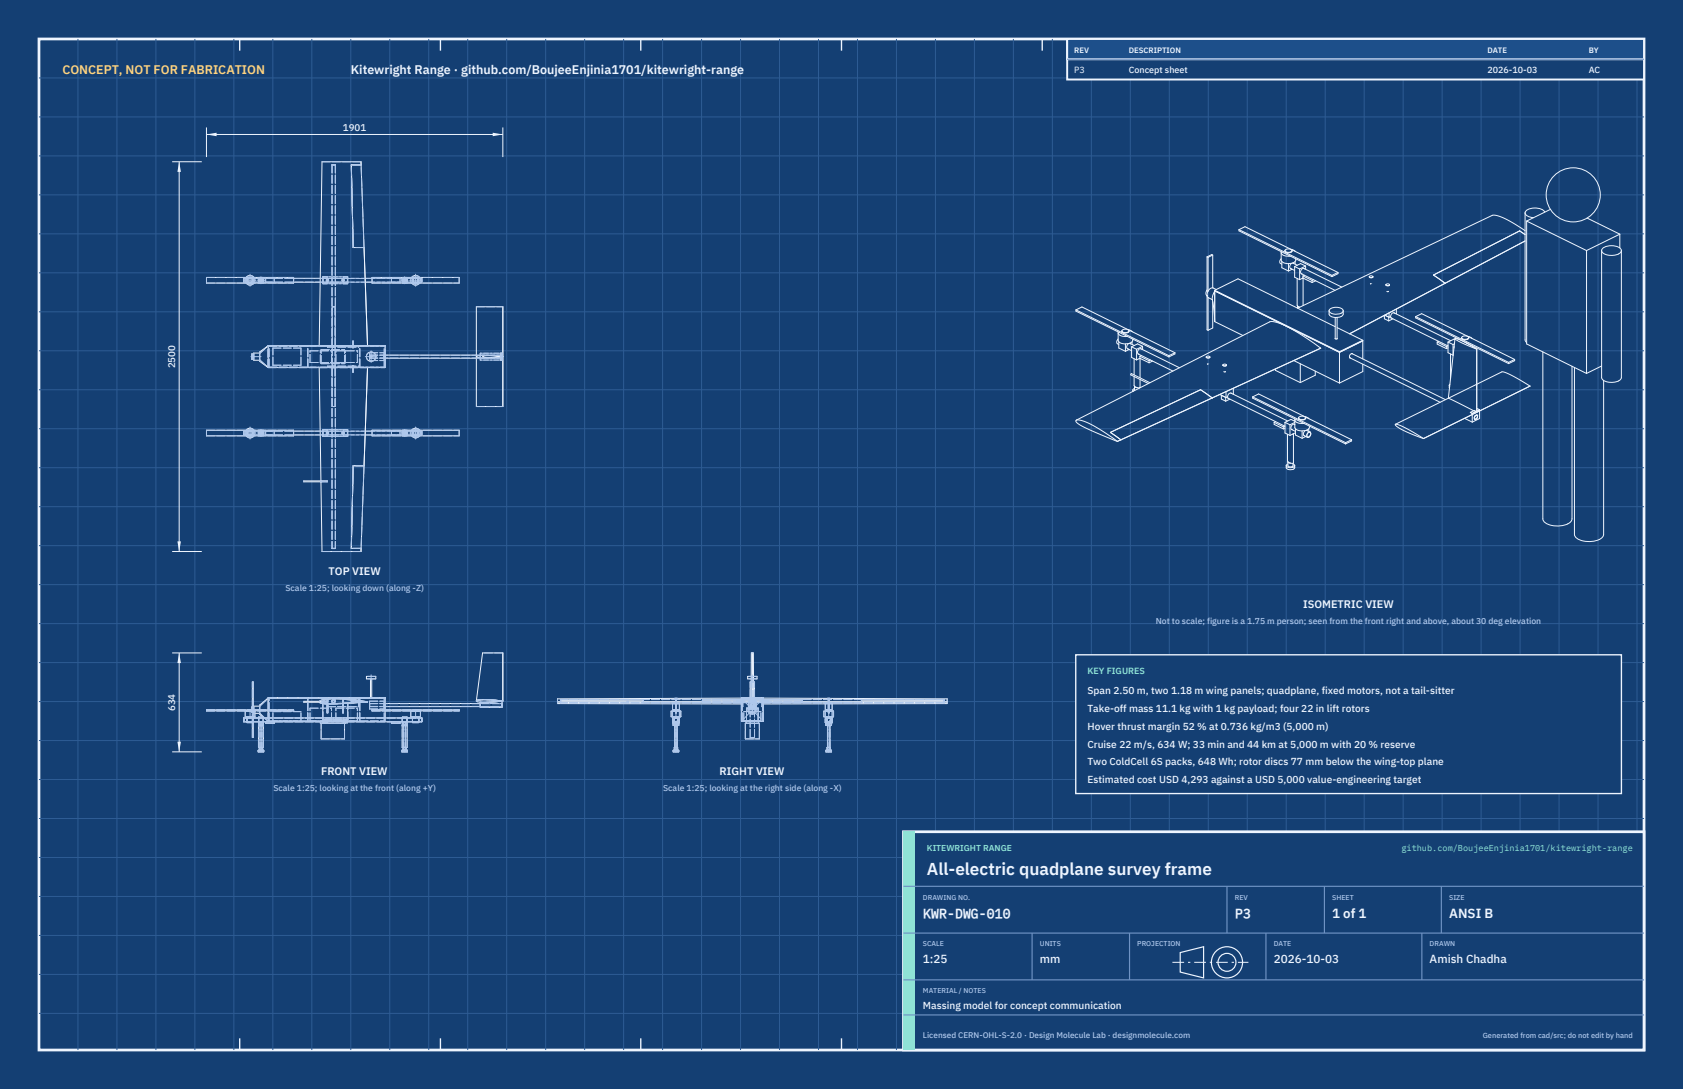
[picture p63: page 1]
CONCEPT, NOT FOR FABRICATION; Kitewright Range · github.com/BoujeeEnjinia1701/kitewright-range; FRONT VIEW; TOP VIEW; RIGHT VIEW; ISOMETRIC VIEW; REV; DESCRIPTION; DATE; Concept sheet; KITEWRIGHT RANGE; github.com/BoujeeEnjinia1701/kitewright-range; DRAWING NO. KWR-DWG-010; REV P3; SHEET 1 of 1; SIZE ANSI B; SCALE 1:25; UNITS mm; PROJECTION; DRAWN Amish Chadha; Licensed CERN-OHL-S-2.0 · Design Molecule Lab · designmolecule.com; Generated from cad/src; do not edit by hand

Scale 1:25; looking down (along -Z)

Not to scale; figure is a 1.75 m person; seen from the front right and above, about 30 deg elevation

KEY FIGURES
Span 2.50 m, two 1.18 m wing panels; quadplane, fixed motors, not a tail-sitter
Take-off mass 11.1 kg with 1 kg payload; four 22 in lift rotors
Hover thrust margin 52 % at 0.736 kg/m3 (5,000 m)
Cruise 22 m/s, 634 W; 33 min and 44 km at 5,000 m with 20 % reserve
Two ColdCell 6S packs, 648 Wh; rotor discs 77 mm below the wing-top plane
Estimated cost USD 4,293 against a USD 5,000 value-engineering target

Scale 1:25; looking at the front (along +Y)

Scale 1:25; looking at the right side (along -X)

All-electric quadplane survey frame

MATERIAL / NOTES
Massing model for concept communication

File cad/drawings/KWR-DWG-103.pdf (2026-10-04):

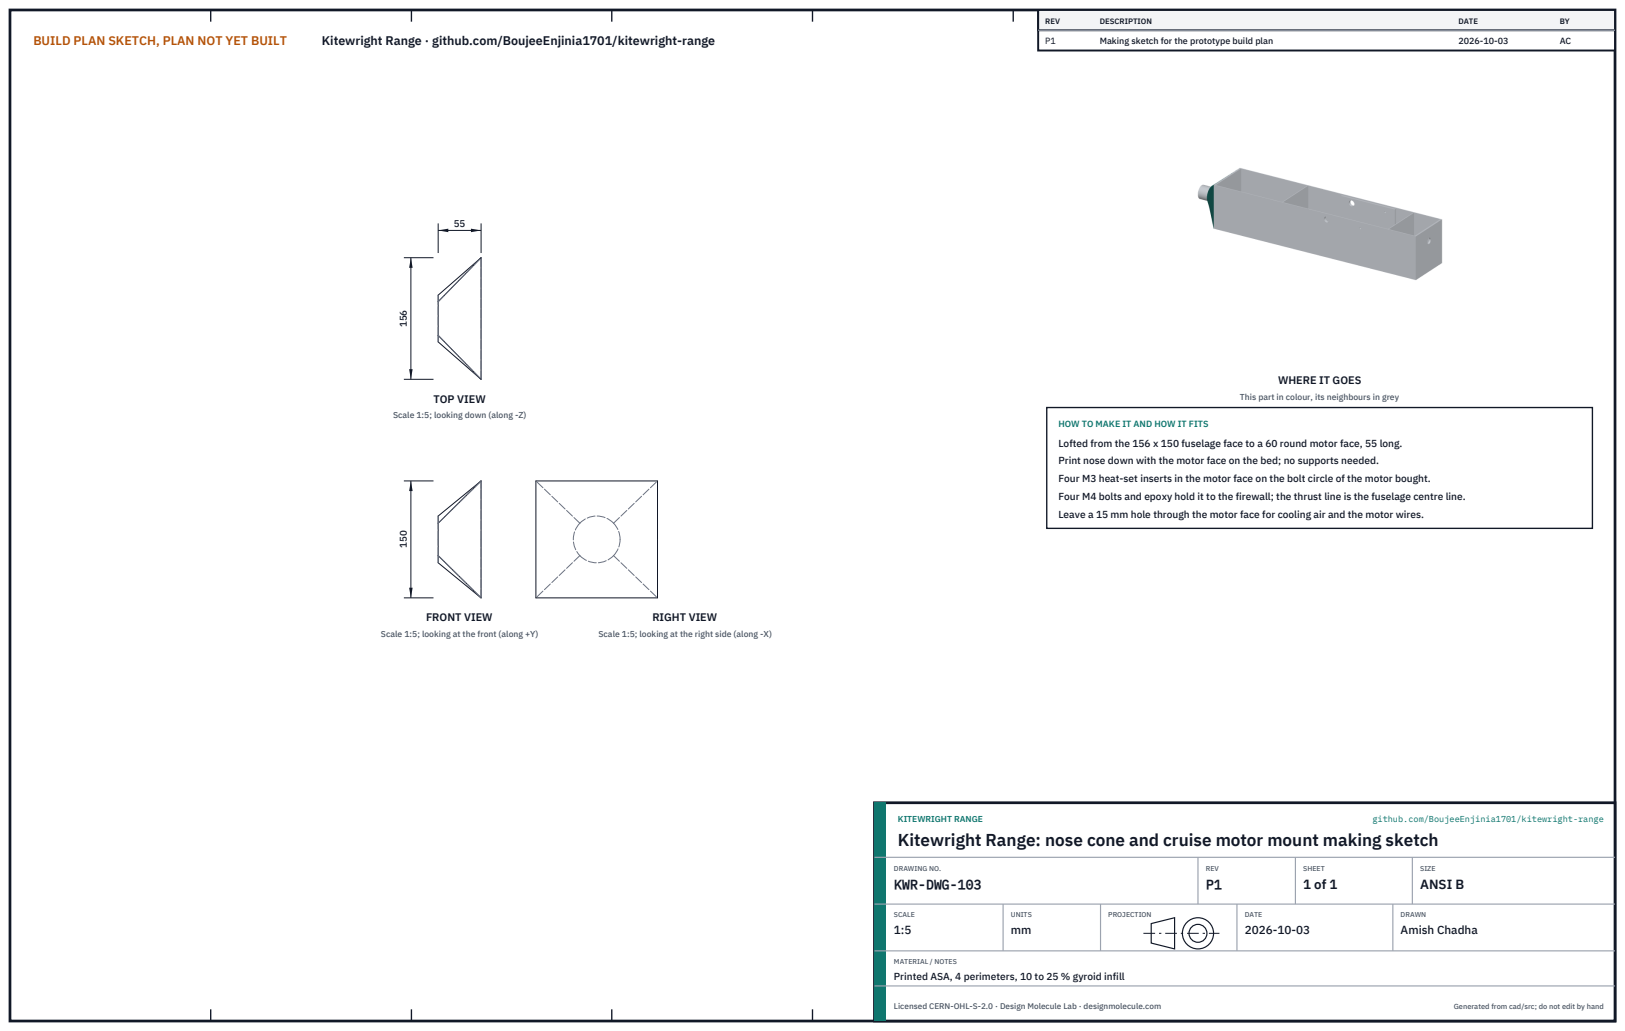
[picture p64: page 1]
BUILD PLAN SKETCH, PLAN NOT YET BUILT; Kitewright Range · github.com/BoujeeEnjinia1701/kitewright-range; FRONT VIEW; TOP VIEW; RIGHT VIEW; REV; DESCRIPTION; DATE; Making sketch for the prototype build plan; KITEWRIGHT RANGE; github.com/BoujeeEnjinia1701/kitewright-range; DRAWING NO. KWR-DWG-103; REV P1; SHEET 1 of 1; SIZE ANSI B; SCALE 1:5; UNITS mm; PROJECTION; DRAWN Amish Chadha; Licensed CERN-OHL-S-2.0 · Design Molecule Lab · designmolecule.com; Generated from cad/src; do not edit by hand

WHERE IT GOES

This part in colour, its neighbours in grey

Scale 1:5; looking down (along -Z)

HOW TO MAKE IT AND HOW IT FITS
Lofted from the 156 x 150 fuselage face to a 60 round motor face, 55 long.
Print nose down with the motor face on the bed; no supports needed.
Four M3 heat-set inserts in the motor face on the bolt circle of the motor bought.
Four M4 bolts and epoxy hold it to the firewall; the thrust line is the fuselage centre line.
Leave a 15 mm hole through the motor face for cooling air and the motor wires.

Scale 1:5; looking at the front (along +Y)

Scale 1:5; looking at the right side (along -X)

Kitewright Range: nose cone and cruise motor mount making sketch

MATERIAL / NOTES
Printed ASA, 4 perimeters, 10 to 25 % gyroid infill

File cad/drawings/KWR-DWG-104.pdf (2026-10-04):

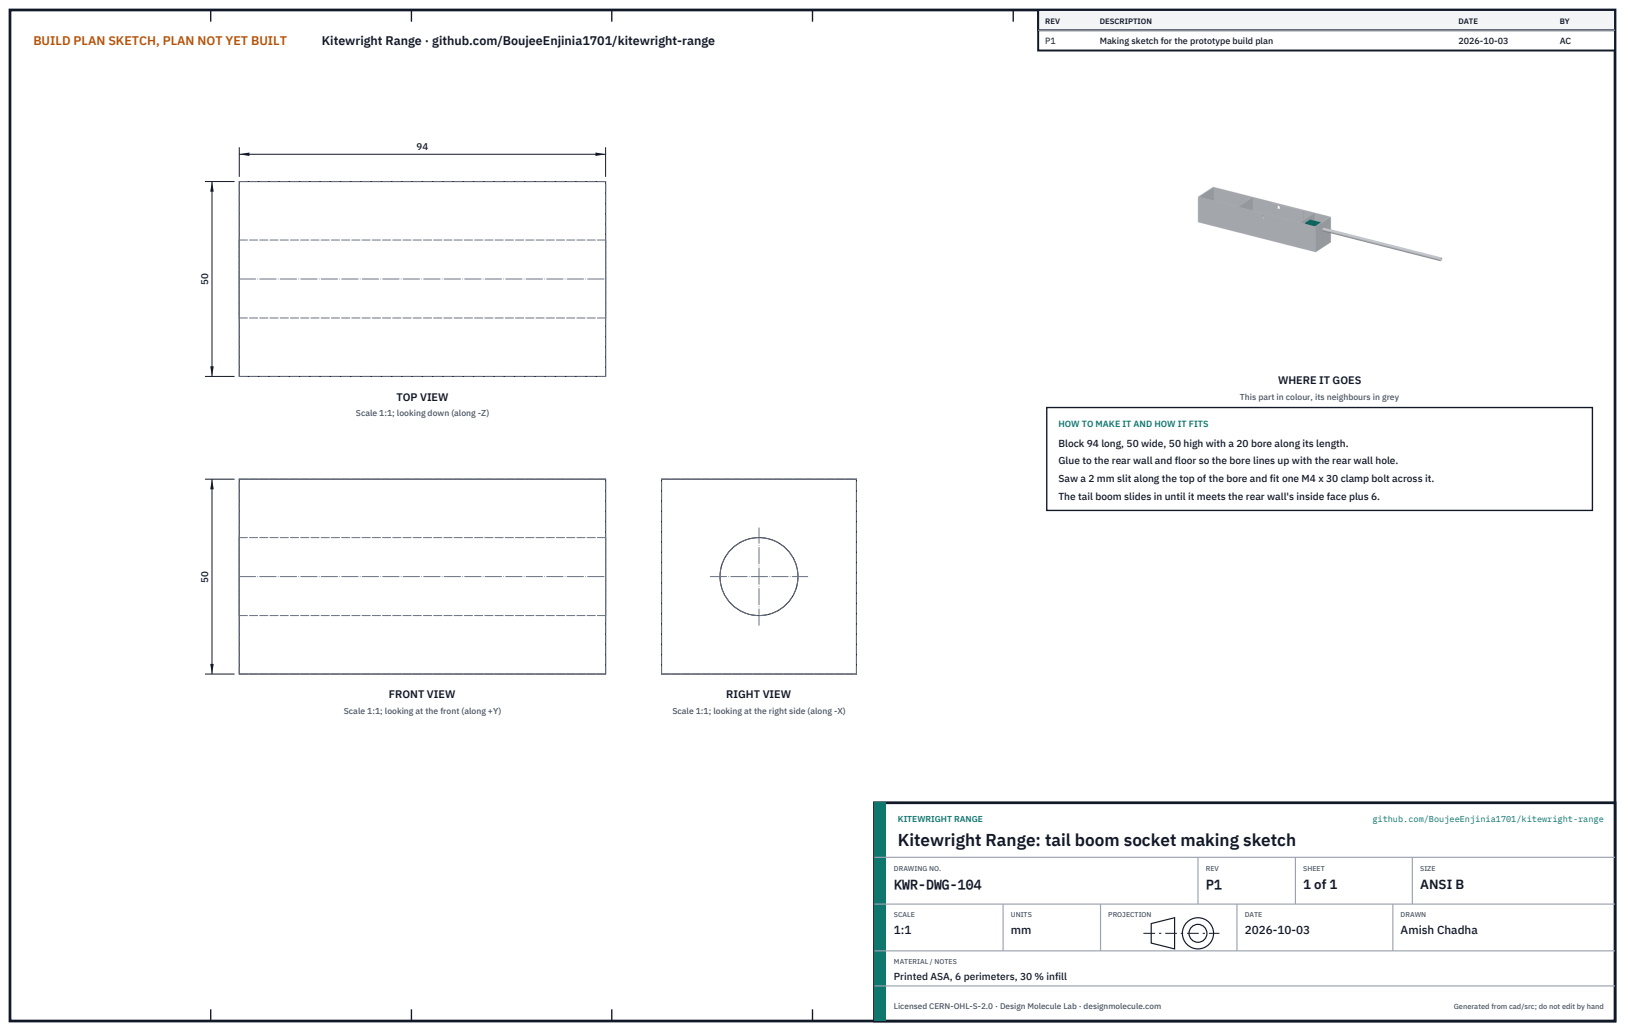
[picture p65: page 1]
BUILD PLAN SKETCH, PLAN NOT YET BUILT; Kitewright Range · github.com/BoujeeEnjinia1701/kitewright-range; FRONT VIEW; TOP VIEW; RIGHT VIEW; REV; DESCRIPTION; DATE; Making sketch for the prototype build plan; KITEWRIGHT RANGE; github.com/BoujeeEnjinia1701/kitewright-range; DRAWING NO. KWR-DWG-104; REV P1; SHEET 1 of 1; SIZE ANSI B; SCALE 1:1; UNITS mm; PROJECTION; DRAWN Amish Chadha; Licensed CERN-OHL-S-2.0 · Design Molecule Lab · designmolecule.com; Generated from cad/src; do not edit by hand

WHERE IT GOES

This part in colour, its neighbours in grey

Scale 1:1; looking down (along -Z)

HOW TO MAKE IT AND HOW IT FITS
Block 94 long, 50 wide, 50 high with a 20 bore along its length.
Glue to the rear wall and floor so the bore lines up with the rear wall hole.
Saw a 2 mm slit along the top of the bore and fit one M4 x 30 clamp bolt across it.
The tail boom slides in until it meets the rear wall's inside face plus 6.

Scale 1:1; looking at the front (along +Y)

Scale 1:1; looking at the right side (along -X)

Kitewright Range: tail boom socket making sketch

MATERIAL / NOTES
Printed ASA, 6 perimeters, 30 % infill

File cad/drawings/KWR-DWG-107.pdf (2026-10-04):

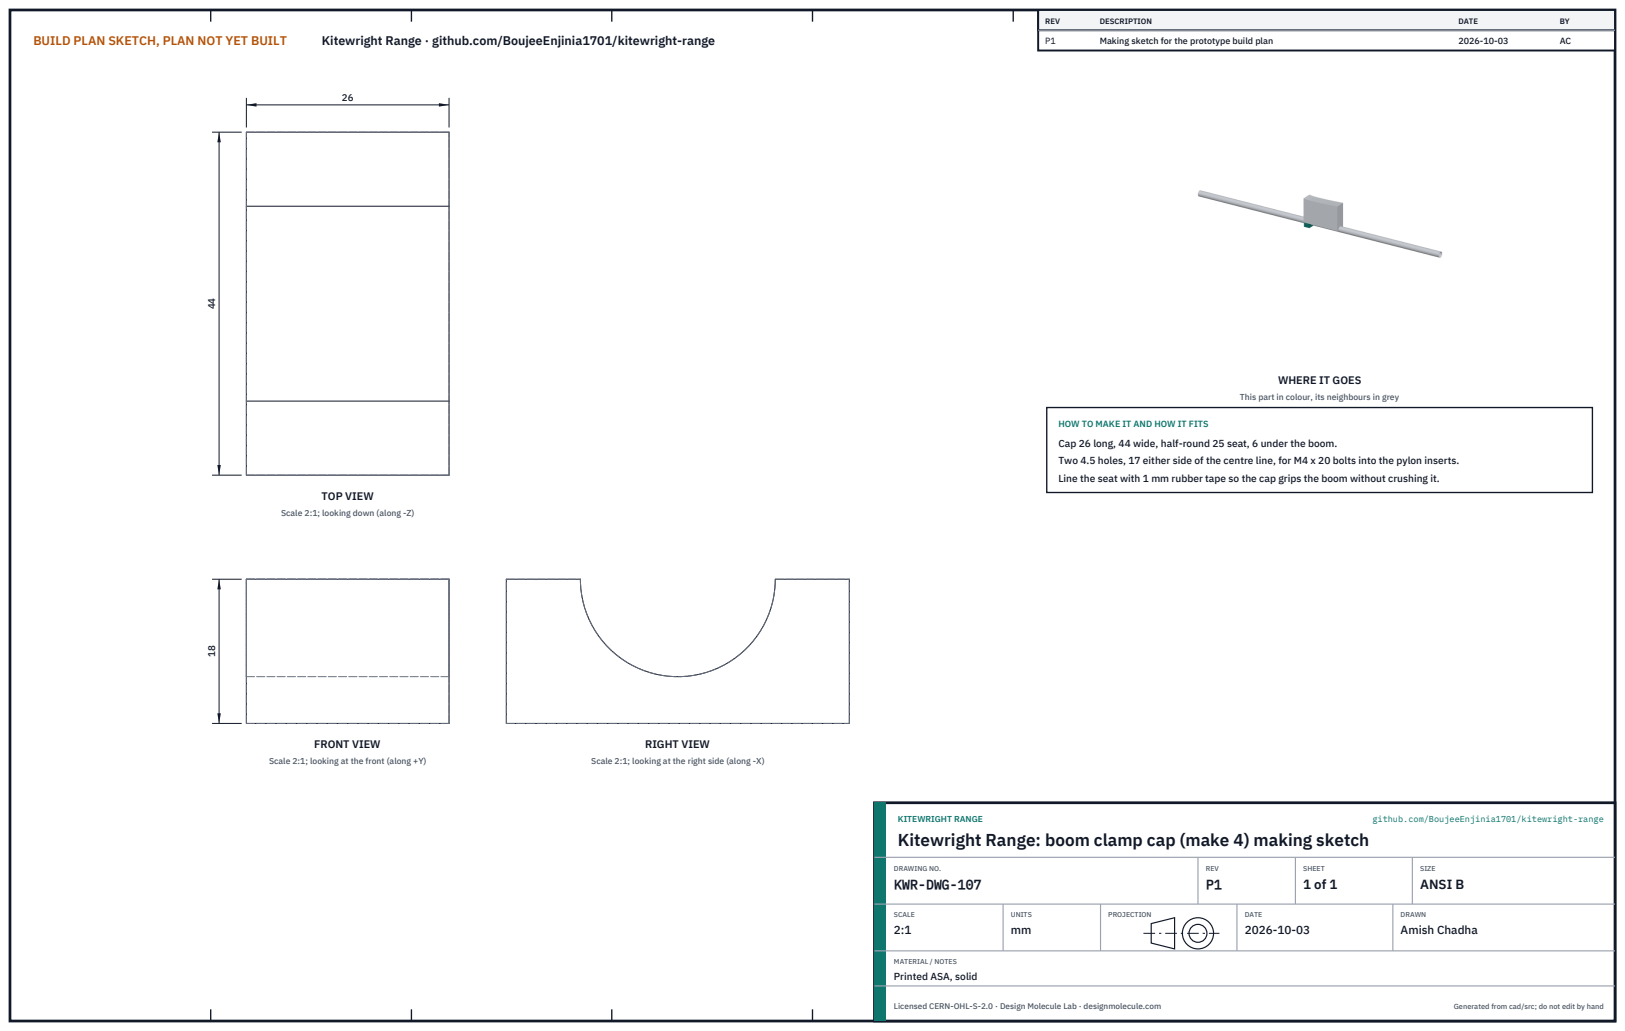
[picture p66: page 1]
BUILD PLAN SKETCH, PLAN NOT YET BUILT; Kitewright Range · github.com/BoujeeEnjinia1701/kitewright-range; FRONT VIEW; TOP VIEW; RIGHT VIEW; REV; DESCRIPTION; DATE; Making sketch for the prototype build plan; KITEWRIGHT RANGE; github.com/BoujeeEnjinia1701/kitewright-range; DRAWING NO. KWR-DWG-107; REV P1; SHEET 1 of 1; SIZE ANSI B; SCALE 2:1; UNITS mm; PROJECTION; DRAWN Amish Chadha; Licensed CERN-OHL-S-2.0 · Design Molecule Lab · designmolecule.com; Generated from cad/src; do not edit by hand

WHERE IT GOES

This part in colour, its neighbours in grey

HOW TO MAKE IT AND HOW IT FITS
Cap 26 long, 44 wide, half-round 25 seat, 6 under the boom.
Two 4.5 holes, 17 either side of the centre line, for M4 x 20 bolts into the pylon inserts.
Line the seat with 1 mm rubber tape so the cap grips the boom without crushing it.

Scale 2:1; looking down (along -Z)

Scale 2:1; looking at the front (along +Y)

Scale 2:1; looking at the right side (along -X)

Kitewright Range: boom clamp cap (make 4) making sketch

MATERIAL / NOTES
Printed ASA, solid

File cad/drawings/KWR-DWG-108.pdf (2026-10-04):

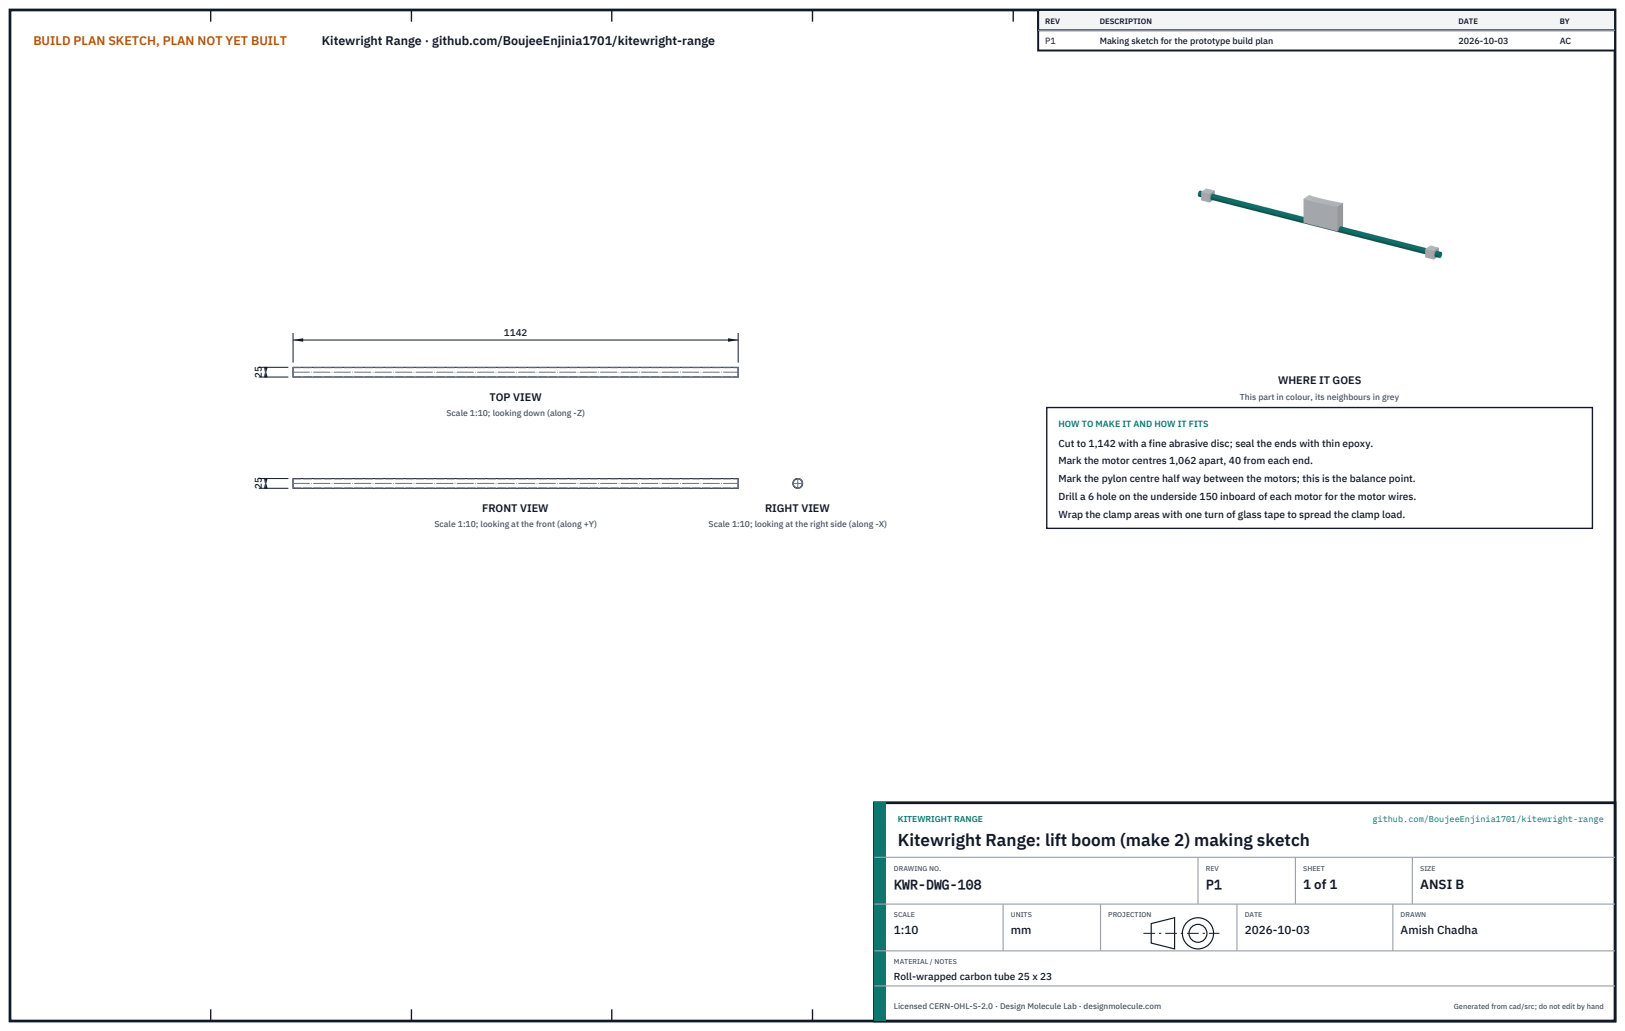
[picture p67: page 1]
BUILD PLAN SKETCH, PLAN NOT YET BUILT; Kitewright Range · github.com/BoujeeEnjinia1701/kitewright-range; FRONT VIEW; TOP VIEW; RIGHT VIEW; REV; DESCRIPTION; DATE; Making sketch for the prototype build plan; KITEWRIGHT RANGE; github.com/BoujeeEnjinia1701/kitewright-range; DRAWING NO. KWR-DWG-108; REV P1; SHEET 1 of 1; SIZE ANSI B; SCALE 1:10; UNITS mm; PROJECTION; DRAWN Amish Chadha; Licensed CERN-OHL-S-2.0 · Design Molecule Lab · designmolecule.com; Generated from cad/src; do not edit by hand

WHERE IT GOES

This part in colour, its neighbours in grey

Scale 1:10; looking down (along -Z)

HOW TO MAKE IT AND HOW IT FITS
Cut to 1,142 with a fine abrasive disc; seal the ends with thin epoxy.
Mark the motor centres 1,062 apart, 40 from each end.
Mark the pylon centre half way between the motors; this is the balance point.
Drill a 6 hole on the underside 150 inboard of each motor for the motor wires.
Wrap the clamp areas with one turn of glass tape to spread the clamp load.

Scale 1:10; looking at the front (along +Y)

Scale 1:10; looking at the right side (along -X)

Kitewright Range: lift boom (make 2) making sketch

MATERIAL / NOTES
Roll-wrapped carbon tube 25 x 23

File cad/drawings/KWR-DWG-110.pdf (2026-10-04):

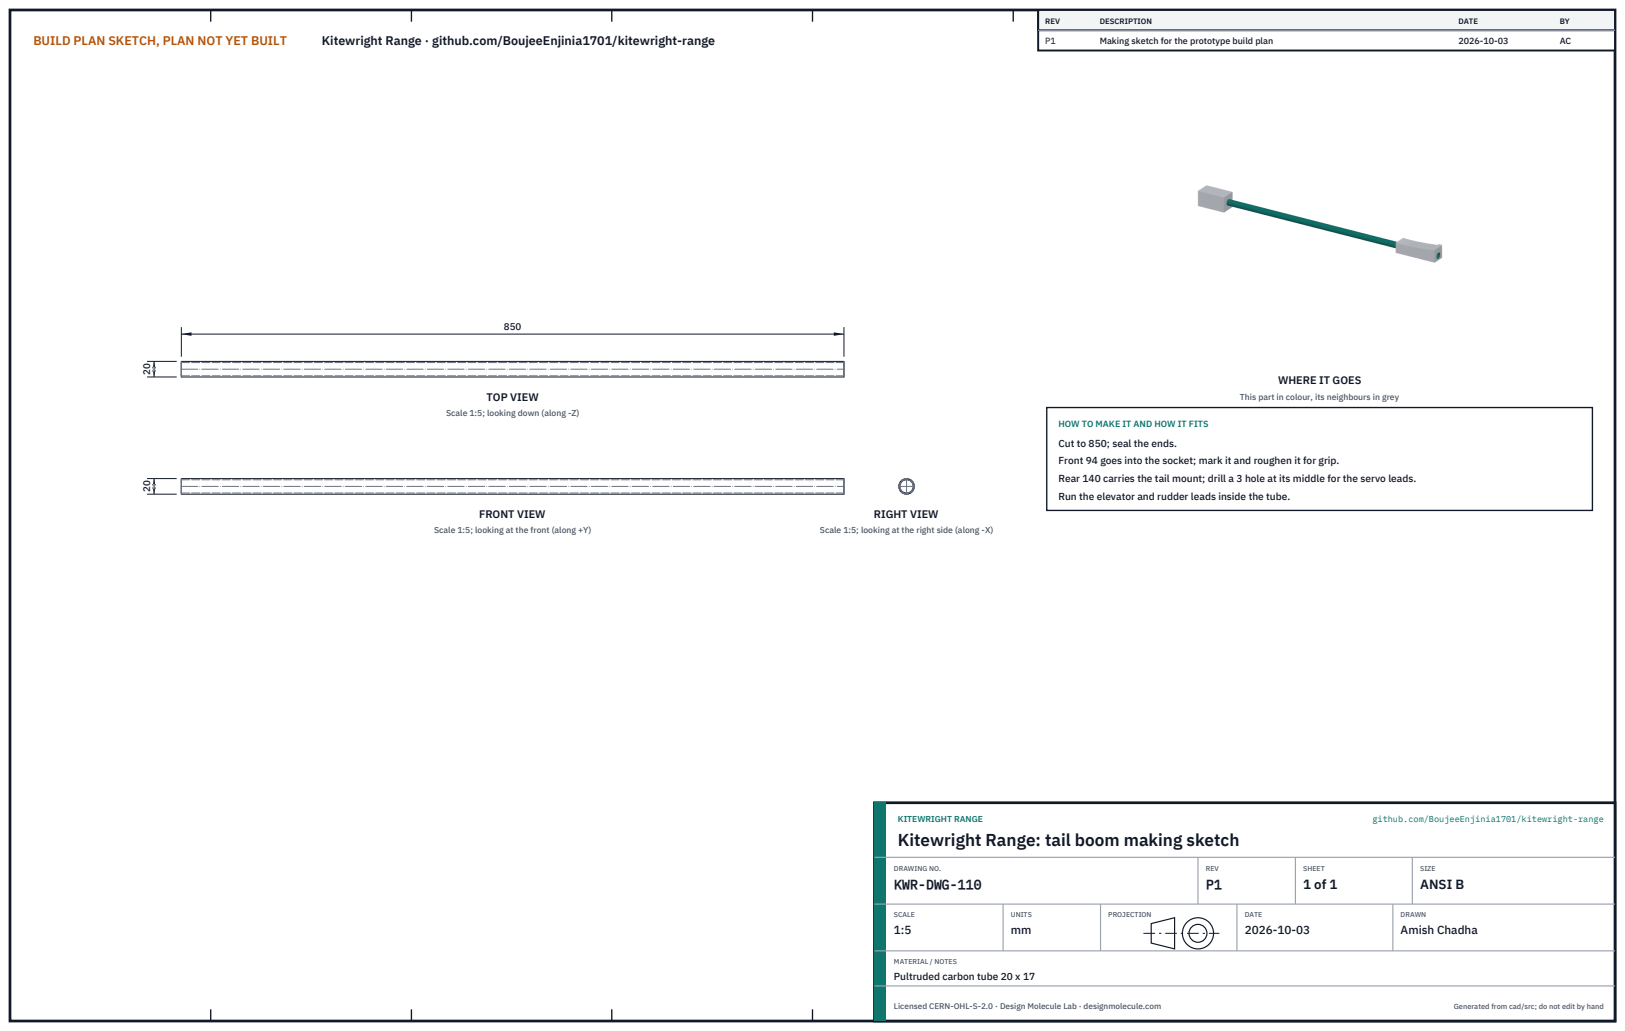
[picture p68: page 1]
BUILD PLAN SKETCH, PLAN NOT YET BUILT; Kitewright Range · github.com/BoujeeEnjinia1701/kitewright-range; FRONT VIEW; TOP VIEW; RIGHT VIEW; REV; DESCRIPTION; DATE; Making sketch for the prototype build plan; KITEWRIGHT RANGE; github.com/BoujeeEnjinia1701/kitewright-range; DRAWING NO. KWR-DWG-110; REV P1; SHEET 1 of 1; SIZE ANSI B; SCALE 1:5; UNITS mm; PROJECTION; DRAWN Amish Chadha; Licensed CERN-OHL-S-2.0 · Design Molecule Lab · designmolecule.com; Generated from cad/src; do not edit by hand

WHERE IT GOES

This part in colour, its neighbours in grey

Scale 1:5; looking down (along -Z)

HOW TO MAKE IT AND HOW IT FITS
Cut to 850; seal the ends.
Front 94 goes into the socket; mark it and roughen it for grip.
Rear 140 carries the tail mount; drill a 3 hole at its middle for the servo leads.
Run the elevator and rudder leads inside the tube.

Scale 1:5; looking at the front (along +Y)

Scale 1:5; looking at the right side (along -X)

Kitewright Range: tail boom making sketch

MATERIAL / NOTES
Pultruded carbon tube 20 x 17

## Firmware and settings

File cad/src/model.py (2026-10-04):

"""Kitewright Range parametric model (build123d), TRL 3, constructable design (KWR-DDR-002, KWR-DDR-003).

Run from the repo root:  python cad/src/model.py
Builds every component of the all-electric quadplane from PARAMS, runs the constructability
checks (no overlaps, nothing floating, design-around geometry, transport lengths) and exports
STEP and STL files to cad/step and cad/stl.

Axes and units: millimetres. X runs from the nose (firewall at x = 0) toward the tail, Y is to
the right wing (+Y is the right wing seen from behind), Z is up with the ground at z = 0 when the
aircraft stands on its landing feet. The wing spar line is straight at 30 % chord.

The Kitewright Core hangs under the fuselage floor at the centre of gravity to the family envelope
(core_envelope.py, the Kitewright interface table of 2026-10-04, decision 10A): four M4 hard points on a
220 x 130 mm pattern in a 6 mm birch doubler on the floor, its lid up through a 200 x 112 mm opening, its
rail and payload shoe under the fuselage. The Core's GNSS receiver rides the hatch mast and its antennas
go to the hatch on extension leads.

PRELIMINARY, NOT FOR FABRICATION. Every size here is a TRL 3 design figure; bought parts are
envelopes of a specification, not of a named product.
"""
from __future__ import annotations

import math
import sys
from pathlib import Path

from build123d import (Box, Compound, Cylinder, Face, Line, Location, Plane, Polyline, Pos, Rot, Solid,
                       Spline, Wire, export_step, export_stl, extrude, loft, make_face)

ROOT = Path(__file__).resolve().parents[2]
sys.path.insert(0, str(Path(__file__).resolve().parent))
import core_envelope as CE  # noqa: E402

PARAMS = {
    # fuselage box (3 mm birch ply, glass cloth outside)
    "fus_len": 750.0, "fus_w": 156.0, "fus_h": 150.0, "fus_z0": 195.0, "ply": 3.0, "ply_thick": 6.0,   # 156 wide: 150 inside for the Core (decision 10A; was 140)
    "bulkheads": (252.0, 645.0),            # x of the two inner bulkheads (front faces); rear one moved aft from 585 for the rear pack (10A)
    "doubler_x": (380.0, 580.0), "doubler_z": (290.0, 342.0),
    "hatch_t": 3.0,
    # nose cone and cruise drive
    "nose_len": 55.0, "nose_tip_d": 60.0, "cruise_motor_d": 46.0, "cruise_motor_l": 38.0,
    "cruise_prop_d": 356.0,                 # 14 in folding propeller
    "thrust_line_z": 270.0,
    # wing (NACA 2412, straight spar at 30 % chord, no sweep of the spar line, no dihedral)
    "root_chord": 310.0, "tip_chord": 250.0, "panel_span": 1180.0, "spar_x": 420.0, "chord_z": 320.0,
    "spar_z": 325.0, "spar_od": 22.0, "spar_id": 20.0, "joiner_od": 20.0, "joiner_id": 16.0, "joiner_len": 640.0,
    "aileron_y": (700.0, 1230.0), "hinge_frac": 0.75,
    "wing_bolt_x": 544.0, "wing_bolt_z": 324.0,
    # lift system
    "boom_y": 490.0, "boom_z": 205.0, "boom_od": 25.0, "boom_id": 23.0, "motor_half_span": 531.0,
    "boom_overhang": 40.0,
    "pylon_x": (350.0, 510.0), "pylon_w": 44.0, "pylon_bolts_x": (380.0, 480.0),
    "clamp_x": ((352.0, 378.0), (482.0, 508.0)), "clamp_t": 6.0,
    "lift_motor_d": 62.0, "lift_motor_h": 36.0, "mount_h": 20.0, "lift_prop_d": 558.8,   # 22 in propellers on 5215-class motors (KWR-DDR-003)
    "leg_inset": 70.0, "leg_rod_d": 12.0, "foot_d": 36.0, "leg_fair": (32.0, 16.0),
    # tail
    "tail_boom_od": 20.0, "tail_boom_id": 17.0, "tail_boom_x": (650.0, 1500.0), "tail_z": 300.0,
    "stab_chord": 170.0, "stab_span": 640.0, "stab_le": 1335.0, "stab_z": 326.0,
    "fin_root": 170.0, "fin_tip": 130.0, "fin_h": 300.0,
    # bays and the Kitewright Core to the family envelope (core_envelope.py, decision 10A)
    "pack": (138.0, 75.0, 82.0), "pack_x": (60.0, 506.0),   # front pack in the nose bay, rear pack behind the Core lid (10A)
    "core_deck": (300.0, 6.0),                # birch doubler on the floor carrying the Core's four M4 hard points: length, thickness
    "payload": (140.0, 88.0, 100.0),          # payload body under its shoe: inside the Core's 88 mm neck and clear of its pigtail plug
    "gnss_x": 660.0, "gnss_mast": 120.0,
    "pitot_y": -800.0,
    # rules
    "x_cg_frac": 0.28,                      # target centre of gravity, fraction of the mean chord
    "disc_clear_min": 70.0,                 # rotor discs at least this far below the wing-top plane
    "case_len": 1300.0,                     # longest transport case
}


# ----------------------------------------------------------------------------- derived figures
def chord(y, P=PARAMS):
    t = (abs(y) - P["fus_w"] / 2) / P["panel_span"]
    return P["root_chord"] + (P["tip_chord"] - P["root_chord"]) * min(max(t, 0.0), 1.0)


def le_x(y, P=PARAMS):
    return P["spar_x"] - 0.3 * chord(y, P)


def naca(xc, t=0.12, m=0.02, p=0.4):
    """Upper and lower surface heights (fractions of chord) of a NACA 4-digit section at xc."""
    yt = 5 * t * (0.2969 * math.sqrt(xc) - 0.1260 * xc - 0.3516 * xc ** 2 + 0.2843 * xc ** 3 - 0.1015 * xc ** 4)
    if m == 0:
        return yt, -yt
    yc = m / p ** 2 * (2 * p * xc - xc ** 2) if xc < p else m / (1 - p) ** 2 * ((1 - 2 * p) + 2 * p * xc - xc ** 2)
    return yc + yt, yc - yt


def surface_z(x, y, upper=True, P=PARAMS):
    c = chord(y, P)
    xc = (x - le_x(y, P)) / c
    u, l = naca(min(max(xc, 0.0), 1.0))
    return P["chord_z"] + (u if upper else l) * c


def derived(P=PARAMS):
    D = {}
    cr, ct = P["root_chord"], P["tip_chord"]
    lam = ct / cr
    D["span"] = 2 * P["panel_span"] + P["fus_w"]
    D["wing_area_m2"] = (2 * P["panel_span"] * (cr + ct) / 2 + P["fus_w"] * cr) / 1e6
    D["mac"] = 2 / 3 * cr * (1 + lam + lam ** 2) / (1 + lam)
    D["y_mac"] = P["fus_w"] / 2 + P["panel_span"] / 3 * (1 + 2 * lam) / (1 + lam)
    D["x_le_mac"] = P["spar_x"] - 0.3 * D["mac"]
    D["x_cg"] = round(D["x_le_mac"] + P["x_cg_frac"] * D["mac"], 1)
    D["aspect_ratio"] = D["span"] ** 2 / (D["wing_area_m2"] * 1e6)
    D["motor_x"] = (D["x_cg"] - P["motor_half_span"], D["x_cg"] + P["motor_half_span"])
    D["boom_x"] = (D["motor_x"][0] - P["boom_overhang"], D["motor_x"][1] + P["boom_overhang"])
    D["boom_len"] = D["boom_x"][1] - D["boom_x"][0]
    D["mount_top"] = P["boom_z"] + P["mount_h"]
    D["motor_top"] = D["mount_top"] + P["lift_motor_h"]
    D["disc_z"] = D["motor_top"] + 5.0                     # propeller blade mid-plane
    yb = P["boom_y"]
    D["wing_top_at_boom"] = max(surface_z(le_x(yb, P) + f * chord(yb, P), yb, True, P) for f in [i / 50 for i in range(51)])
    D["disc_below_wing_top"] = D["wing_top_at_boom"] - D["disc_z"]
    D["front_disc_to_le"] = le_x(yb, P) - (D["motor_x"][0] + P["lift_prop_d"] / 2)
    D["rear_disc_to_te"] = (D["motor_x"][1] - P["lift_prop_d"] / 2) - (le_x(yb, P) + chord(yb, P))
    # lift disc against the cruise propeller disc (vertical plane at the cruise propeller)
    xp = -P["nose_len"] - P["cruise_motor_l"] - 12.0
    dx = abs(xp - D["motor_x"][0])
    half = math.sqrt(max((P["lift_prop_d"] / 2) ** 2 - dx ** 2, 0.0))
    D["cruise_prop_x"] = xp
    D["lift_to_cruise_disc_y"] = (yb - half) - P["cruise_prop_d"] / 2
    D["rear_disc_to_stab"] = P["stab_le"] - (D["motor_x"][1] + P["lift_prop_d"] / 2)
    D["lift_disc_to_fus"] = yb - P["lift_prop_d"] / 2 - P["fus_w"] / 2
    D["leg_x"] = (D["motor_x"][0] + P["leg_inset"], D["motor_x"][1] - P["leg_inset"])
    D["leg_top"] = P["boom_z"] - P["boom_od"] / 2
    D["core_z"] = P["fus_z0"] - CE.CORE["spacer"][2]          # Core plate top: the floor underside is its deck
    D["shoe_bot"] = D["core_z"] + CE.CORE["shoe"][3]
    D["ground_to_payload"] = D["shoe_bot"] - P["payload"][2]
    D["ground_to_core_knobs"] = D["core_z"] + CE.CORE["knob"][1]
    D["ground_to_cruise_tip"] = P["thrust_line_z"] - P["cruise_prop_d"] / 2
    D["tail_arm"] = P["stab_le"] + 0.25 * P["stab_chord"] - (D["x_le_mac"] + 0.25 * D["mac"])
    D["stab_area_m2"] = P["stab_chord"] * P["stab_span"] / 1e6
    D["fin_area_m2"] = (P["fin_root"] + P["fin_tip"]) / 2 * P["fin_h"] / 1e6
    D["vh"] = D["stab_area_m2"] * D["tail_arm"] / (D["wing_area_m2"] * D["mac"])
    D["vv"] = D["fin_area_m2"] * D["tail_arm"] / (D["wing_area_m2"] * D["span"])
    D["lift_disc_area_m2"] = 4 * math.pi * (P["lift_prop_d"] / 2000) ** 2
    D["overall_len"] = P["tail_boom_x"][1] + 10 - D["cruise_prop_x"]
    D["fin_top"] = P["stab_z"] + 0.05 * P["stab_chord"] + P["fin_h"]
    return D


# ----------------------------------------------------------------------------- geometry helpers
def _airfoil_face(c, x_le, y, z0, t=0.12, m=0.02, n=36):
    xs = [0.5 * (1 - math.cos(math.pi * i / n)) for i in range(n + 1)]   # 0 (LE) to 1 (TE)
    up = [(x_le + x * c, y, z0 + naca(x, t, m)[0] * c) for x in xs]
    lo = [(x_le + x * c, y, z0 + naca(x, t, m)[1] * c) for x in xs]
    pts = list(reversed(up)) + lo[1:]
    w = Wire([Spline(*pts), Line(pts[-1], pts[0])])
    return Face(w)


def _vert_airfoil_face(c, x_le, z, t=0.10, n=30):
    """Symmetric section lying in a horizontal plane at height z (for the fin), thickness along Y."""
    xs = [0.5 * (1 - math.cos(math.pi * i / n)) for i in range(n + 1)]
    up = [(x_le + x * c, naca(x, t, 0)[0] * c, z) for x in xs]
    lo = [(x_le + x * c, naca(x, t, 0)[1] * c, z) for x in xs]
    pts = list(reversed(up)) + lo[1:]
    return Face(Wire([Spline(*pts), Line(pts[-1], pts[0])]))


def box(x0, x1, y0, y1, z0, z1):
    return Pos((x0 + x1) / 2, (y0 + y1) / 2, (z0 + z1) / 2) * Box(x1 - x0, y1 - y0, z1 - z0)


def cyl_x(x0, x1, y, z, d):
    return Pos((x0 + x1) / 2, y, z) * Rot(0, 90, 0) * Cylinder(d / 2, x1 - x0)


def cyl_y(y0, y1, x, z, d):
    return Pos(x, (y0 + y1) / 2, z) * Rot(90, 0, 0) * Cylinder(d / 2, y1 - y0)


def cyl_z(z0, z1, x, y, d):
    return Pos(x, y, (z0 + z1) / 2) * Cylinder(d / 2, z1 - z0)


def tube_x(x0, x1, y, z, od, idia):
    return cyl_x(x0, x1, y, z, od) - cyl_x(x0 - 1, x1 + 1, y, z, idia)


def tube_y(y0, y1, x, z, od, idia):
    return cyl_y(y0, y1, x, z, od) - cyl_y(y0 - 1, y1 + 1, x, z, idia)


def mirror_y(shape):
    from build123d import Plane as _P, mirror
    return mirror(shape, about=_P.XZ)


# ----------------------------------------------------------------------------- components
def wing_solid(side=1, P=PARAMS):
    """Outer mould line of one wing panel (side +1 right, -1 left), root rib face at |y| = fus_w / 2."""
    y0 = P["fus_w"] / 2
    y1 = y0 + P["panel_span"]
    fr = _airfoil_face(chord(y0, P), le_x(y0, P), y0, P["chord_z"])
    ft = _airfoil_face(chord(y1, P), le_x(y1, P), y1, P["chord_z"])
    s = loft([fr, ft], ruled=True)
    return s if side > 0 else mirror_y(s)


def aileron_cutter(side=1, P=PARAMS):
    ya, yb = P["aileron_y"]
    h = P["hinge_frac"]
    pts = [(le_x(ya, P) + h * chord(ya, P), ya), (le_x(yb, P) + h * chord(yb, P), yb),
           (le_x(yb, P) + chord(yb, P) + 5, yb), (le_x(ya, P) + chord(ya, P) + 5, ya)]
    if side < 0:
        pts = [(x, -y) for x, y in pts]
    face = make_face(Polyline(*pts, close=True))
    return Pos(0, 0, P["chord_z"] - 60) * extrude(face, 120)


def build_parts(P=PARAMS):
    D = derived(P)
    L, W, H, z0, t = P["fus_len"], P["fus_w"], P["fus_h"], P["fus_z0"], P["ply"]
    z1 = z0 + H
    yb, zb, rb = P["boom_y"], P["boom_z"], P["boom_od"] / 2
    m = {}

    # 1 fuselage box: two sides, floor, firewall, two bulkheads, rear wall, wing-root doublers
    outer = box(0, L, -W / 2, W / 2, z0, z1)
    inner = box(6, L - 6, -W / 2 + t, W / 2 - t, z0 + t, z1 + 1)
    fus = outer - inner
    for xb in P["bulkheads"]:
        fus += box(xb, xb + t, -W / 2 + t, W / 2 - t, z0 + t, z1)
    dx0, dx1 = P["doubler_x"]
    dz0, dz1 = P["doubler_z"]
    th = P["ply_thick"]
    for s in (1, -1):
        y_in = s * (W / 2 - t)
        fus += box(dx0, dx1, min(y_in, y_in - s * th), max(y_in, y_in - s * th), dz0, dz1)
    fus -= cyl_y(-W, W, P["spar_x"], P["spar_z"], P["joiner_od"] + 0.5)
    fus -= cyl_y(-W, W, P["wing_bolt_x"], P["wing_bolt_z"], 5.5)
    fus -= cyl_x(L - 10, L + 1, 0, P["tail_z"], P["tail_boom_od"] + 0.5)
    xc = D["x_cg"]
    ox, oy = CE.CORE["deck_opening"]
    fus -= box(xc - ox / 2, xc + ox / 2, -oy / 2, oy / 2, z0 - 1, z0 + t + 1)          # floor opening for the Core lid
    for fx, fy in CE.frame_points():
        fus -= cyl_z(z0 - 1, z0 + t + 1, xc - fx, fy, 4.3)
    m["fus"] = fus
    # 1a Core deck doubler: 6 mm birch on the floor, the Core's four M4 hard points and the lid opening
    dl, dt = P["core_deck"]
    dk = box(xc - dl / 2, xc + dl / 2, -W / 2 + t, W / 2 - t, z0 + t, z0 + t + dt)
    dk -= box(xc - ox / 2, xc + ox / 2, -oy / 2, oy / 2, z0, z0 + t + dt + 1)
    for fx, fy in CE.frame_points():
        dk -= cyl_z(z0, z0 + t + dt + 1, xc - fx, fy, 4.3)
    m["core_deck"] = dk

    # 2 hatch (3 mm ply) with the GNSS mast hole
    m["hatch"] = box(0, L, -W / 2, W / 2, z1, z1 + P["hatch_t"]) - cyl_z(z1 - 1, z1 + 10, P["gnss_x"], 0, 8.5)

    # 3 nose cone and cruise motor mount (printed ASA), hollow behind a 6 mm motor face
    from build123d import Rectangle, Circle
    zt = P["thrust_line_z"]
    rect = Plane(origin=(0, 0, (z0 + z1) / 2), x_dir=(0, 1, 0), z_dir=(1, 0, 0)) * Rectangle(W, H)
    tip = Plane(origin=(-P["nose_len"], 0, zt), x_dir=(0, 1, 0), z_dir=(1, 0, 0)) * Circle(P["nose_tip_d"] / 2)
    nose = loft([tip, rect])
    m["nose"] = nose

    # 4 tail boom socket (printed), glued inside the rear of the fuselage
    tz = P["tail_z"]
    m["socket"] = box(650, L - 6, -25, 25, tz - 25, tz + 25) - cyl_x(640, L, 0, tz, P["tail_boom_od"])

    # 5, 6 wing panels with spars, root bolt holes, pitot hole; 7 ailerons
    spar_len = P["panel_span"] - 20
    pit_y = P["pitot_y"]
    pit_x0 = le_x(pit_y, P) - 110
    pit_x1 = le_x(pit_y, P) + 40
    pit_z = P["chord_z"] + 1.0
    for side, key in ((1, "r"), (-1, "l")):
        w = wing_solid(side, P)
        y0 = side * W / 2
        spar = tube_y(min(y0, y0 + side * spar_len), max(y0, y0 + side * spar_len), P["spar_x"], P["spar_z"],
                      P["spar_od"], P["spar_id"])
        w -= cyl_y(min(y0, y0 + side * (spar_len + 1)), max(y0, y0 + side * (spar_len + 1)), P["spar_x"], P["spar_z"], P["spar_od"])
        w -= cyl_y(min(y0, y0 + side * 30), max(y0, y0 + side * 30), P["wing_bolt_x"], P["wing_bolt_z"], 5.5)
        for xb in P["pylon_bolts_x"]:
            w -= cyl_z(250, 400, xb, side * yb, 5.5)
        if side < 0:
            w -= cyl_x(pit_x0, pit_x1, pit_y, pit_z, 6.0)
        cut = aileron_cutter(side, P)
        m[f"ail_{key}"] = w & cut
        m[f"wing_{key}"] = w - cut
        m[f"spar_{key}"] = spar

    # 8 joiner tube through the fuselage and into both spars
    m["joiner"] = tube_y(-P["joiner_len"] / 2, P["joiner_len"] / 2, P["spar_x"], P["spar_z"], P["joiner_od"], P["joiner_id"])

    # 9 wing bolts, nylon M5 x 40, head inside the fuselage
    bolts = []
    for s in (1, -1):
        yi = s * (W / 2 - t - th)
        shank = cyl_y(min(yi, s * (W / 2 + 25)), max(yi, s * (W / 2 + 25)), P["wing_bolt_x"], P["wing_bolt_z"], 5.0)
        head = cyl_y(min(yi, yi - s * 4), max(yi, yi - s * 4), P["wing_bolt_x"], P["wing_bolt_z"], 9.0)
        bolts.append(shank + head)
    m["wing_bolts"] = Compound(bolts)

    # 10 boom pylons (printed ASA), conforming to the wing lower skin, saddle on the boom
    px0, px1 = P["pylon_x"]
    pw = P["pylon_w"]
    for side, key in ((1, "r"), (-1, "l")):
        y = side * yb
        py = box(px0, px1, y - pw / 2, y + pw / 2, zb, P["chord_z"] + 10)
        py -= wing_solid(side, P)
        py -= cyl_x(px0 - 1, px1 + 1, y, zb, P["boom_od"])
        for xb in P["pylon_bolts_x"]:
            py -= cyl_z(250, 400, xb, y, 5.5)
        m[f"pylon_{key}"] = py
        # pylon through-bolts M5, from washers on the upper skin down into nuts in the pylon
        pb = []
        for xb in P["pylon_bolts_x"]:
            zt_ = max(surface_z(xb + d, y, True, P) for d in (-7.5, -4, 0, 4, 7.5)) + 0.3
            pb.append(cyl_z(zt_ - 85, zt_ + 0.2, xb, y, 5.0) + cyl_z(zt_ + 0.2, zt_ + 1.7, xb, y, 15.0))
        m[f"pbolts_{key}"] = Compound(pb)
        # 11 clamp caps, two per pylon
        caps = []
        for cx0, cx1 in P["clamp_x"]:
            cap = box(cx0, cx1, y - pw / 2, y + pw / 2, zb - rb - P["clamp_t"], zb) - cyl_x(cx0 - 1, cx1 + 1, y, zb, P["boom_od"])
            caps.append(cap)
        m[f"caps_{key}"] = Compound(caps)
        # 12 lift boom, carbon tube
        m[f"boom_{key}"] = tube_x(D["boom_x"][0], D["boom_x"][1], y, zb, P["boom_od"], P["boom_id"])
        # 13 motor mounts with ESCs (bought aluminium tube clamp mounts)
        mounts, motors, props, escs, legs_c, rods, feet, fairs = [], [], [], [], [], [], [], []
        for k, mx in enumerate(D["motor_x"]):
            mt = box(mx - 20, mx + 20, y - 20, y + 20, zb - rb - 5, D["mount_top"]) - cyl_x(mx - 21, mx + 21, y, zb, P["boom_od"])
            mounts.append(mt)
            motors.append(cyl_z(D["mount_top"], D["motor_top"], mx, y, P["lift_motor_d"]))
            hub = cyl_z(D["motor_top"], D["motor_top"] + 10, mx, y, 30)
            blade = box(mx - P["lift_prop_d"] / 2, mx + P["lift_prop_d"] / 2, y - 18, y + 18, D["motor_top"] + 2, D["motor_top"] + 8)
            props.append(hub + blade)
            ex0, ex1 = (mx + 100, mx + 155) if k == 0 else (mx - 155, mx - 100)
            escs.append(box(ex0, ex1, y - 13, y + 13, zb - rb - 10, zb - rb))
        for lx in D["leg_x"]:
            cl = box(lx - 15, lx + 15, y - 18, y + 18, zb - rb - 22, zb + rb + 5) - cyl_x(lx - 16, lx + 16, y, zb, P["boom_od"])
            cl -= cyl_z(zb - rb - 23, zb - rb - 2, lx, y, P["leg_rod_d"])
            legs_c.append(cl)
            rods.append(cyl_z(8.0, zb - rb - 2, lx, y, P["leg_rod_d"]))
            ft = cyl_z(0, 10, lx, y, P["foot_d"]) + cyl_z(10, 28, lx, y, 22)
            feet.append(ft - cyl_z(8.0, 29, lx, y, P["leg_rod_d"]))
            from build123d import Ellipse
            zf0, zf1 = 28.0, zb - rb - 22
            fair = Pos(lx, y, zf0) * extrude(Ellipse(P["leg_fair"][0] / 2, P["leg_fair"][1] / 2), zf1 - zf0)
            fairs.append(fair - cyl_z(zf0 - 1, zf1 + 1, lx, y, P["leg_rod_d"] + 0.4))
        m[f"mounts_{key}"] = Compound(mounts)
        m[f"motors_{key}"] = Compound(motors)
        m[f"props_{key}"] = Compound(props)
        m[f"escs_{key}"] = Compound(escs)
        m[f"legclamps_{key}"] = Compound(legs_c)
        m[f"legrods_{key}"] = Compound(rods)
        m[f"feet_{key}"] = Compound(feet)
        m[f"legfair_{key}"] = Compound(fairs)

    # 14 cruise motor and folding propeller on the nose cone face
    xm1 = -P["nose_len"]
    xm0 = xm1 - P["cruise_motor_l"]
    m["cruise_motor"] = cyl_x(xm0, xm1, 0, zt, P["cruise_motor_d"])
    spinner = cyl_x(xm0 - 12, xm0, 0, zt, 36)
    blades = box(xm0 - 9, xm0 - 3, -14, 14, zt - P["cruise_prop_d"] / 2, zt + P["cruise_prop_d"] / 2)
    m["cruise_prop"] = spinner + blades

    # 15 tail boom, 16 tail mount, 17 stabiliser, 18 fin
    tx0, tx1 = P["tail_boom_x"]
    m["tail_boom"] = tube_x(tx0, tx1, 0, tz, P["tail_boom_od"], P["tail_boom_id"])
    sx0 = P["stab_le"]
    sc = P["stab_chord"]
    ss = P["stab_span"]
    sz = P["stab_z"]
    s_l = _airfoil_face(sc, sx0, -ss / 2, sz, t=0.10, m=0.0)
    s_r = _airfoil_face(sc, sx0, ss / 2, sz, t=0.10, m=0.0)
    stab = loft([s_l, s_r], ruled=True)
    fx_root = sx0 + sc - P["fin_root"]
    fx_tip = sx0 + sc - P["fin_tip"]
    f0 = _vert_airfoil_face(P["fin_root"], fx_root, sz)
    f1 = _vert_airfoil_face(P["fin_tip"], fx_tip, sz + 0.05 * sc + P["fin_h"])
    fin = loft([f0, f1], ruled=True) - stab
    mount = box(1360, tx1, -22, 22, tz - 15, sz + 2) - stab - fin - cyl_x(1300, tx1 + 5, 0, tz, P["tail_boom_od"])
    m["stab"] = stab
    m["fin"] = fin
    m["tail_mount"] = mount

    # bought and Kitewright Core parts in the bays (envelopes)
    pl, pw_, ph = P["pack"]
    zp = [z0 + t, z0 + t + P["core_deck"][1]]           # the rear pack sits on the Core deck doubler (10A)
    packs = [box(px, px + pl, -pw_ / 2, pw_ / 2, zz, zz + ph) for px, zz in zip(P["pack_x"], zp)]
    m["packs"] = Compound(packs)
    # Kitewright Core (Core repo), turned so its rail points aft: the payload slides in from the tail
    zc = D["core_z"]
    turn = lambda sh: Pos(xc, 0, zc) * Rot(0, 0, 180) * sh   # noqa: E731
    m["core"] = turn(CE.core_body())
    m["mount_plate"] = turn(CE.core_rail() + CE.core_pins() + CE.core_plug())
    al, aw, ah = P["payload"]
    sb = D["shoe_bot"]
    xs = xc - (CE.CORE["shoe"][0] + CE.CORE["shoe"][1]) / 2          # shoe centre (the Core is turned 180 deg)
    m["payload"] = turn(CE.shoe()) + box(xs - al / 2, xs + al / 2, -aw / 2, aw / 2, sb - ah, sb)
    zh = z1 + P["hatch_t"]
    m["gnss"] = cyl_z(z1 - 2, zh + P["gnss_mast"], P["gnss_x"], 0, 8.0) + cyl_z(zh + P["gnss_mast"], zh + P["gnss_mast"] + 16, P["gnss_x"], 0, 60)
    m["pitot"] = cyl_x(pit_x0, pit_x1, pit_y, pit_z, 6.0)
    return m
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

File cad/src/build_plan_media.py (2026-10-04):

"""Kitewright Range build plan pictures (KWR-BLD-001), generated from the constructable model.

Run from the repo root:  python cad/src/build_plan_media.py [overview|sheets|joints|steps]
Writes docs/05-build-plan/overview.png, joint-NN.png and step-NN.png, and the making sketches
cad/drawings/KWR-DWG-101 onward, with .kit/build_views.py. BUILD PLAN ILLUSTRATIONS, PLAN NOT YET BUILT.
"""
import sys
from pathlib import Path

ROOT = Path(__file__).resolve().parents[2]
sys.path[:0] = [str(ROOT / ".kit"), str(ROOT / "cad" / "src")]
from build123d import Compound  # noqa: E402
from build_views import Part, overview, step, joint, component_sheet  # noqa: E402
from model import PARAMS as P, build_parts, derived, box, chord, le_x  # noqa: E402

DATE = "2026-10-03"
OUT = ROOT / "docs" / "05-build-plan"
D = derived(P)
m = build_parts(P)

COL = {"ply": "#D6B98C", "print": "#0F766E", "carbon": "#1F2937", "foam": "#F1F5F9", "metal": "#9CA3AF",
       "elec": "#C2410C", "core": "#16A34A", "pack": "#EA580C", "steel": "#D4A017", "tpu": "#111827"}


def part(key, name, color, explode=(0, 0, 0), shape=None):
    return Part(name, shape if shape is not None else m[key], color, None, explode)


def win(key, x0, x1, y0, y1, z0, z1):
    return m[key] & box(x0, x1, y0, y1, z0, z1)


def comp(*keys):
    return Compound([m[k] for k in keys])


yb, zb = P["boom_y"], P["boom_z"]
mx0, mx1 = D["motor_x"]
lx0, lx1 = D["leg_x"]

# ---------------------------------------------------------------- overview, in build order
GROUPS = [
    ("Fuselage box", comp("fus"), COL["ply"], (0, 0, 0)),
    ("Core deck doubler", comp("core_deck"), COL["ply"], (0, 0, 260)),
    ("Tail boom socket", comp("socket"), COL["print"], (0, 0, 120)),
    ("Nose cone and cruise motor mount", comp("nose"), COL["print"], (-200, 0, 0)),
    ("Cruise motor and folding propeller", comp("cruise_motor", "cruise_prop"), COL["elec"], (-420, 0, 0)),
    ("Kitewright Core, hung under the floor", comp("core"), COL["core"], (0, 0, -220)),
    ("Core rail, locking pins and pigtail (Core)", comp("mount_plate"), COL["metal"], (0, 0, -340)),
    ("Tail boom", comp("tail_boom"), COL["carbon"], (250, 0, 0)),
    ("Tail mount", comp("tail_mount"), COL["print"], (420, 0, -60)),
    ("Stabiliser and fin", comp("stab", "fin"), COL["foam"], (420, 0, 160)),
    ("Wing panels with ailerons and spars", comp("wing_l", "wing_r", "ail_l", "ail_r", "spar_l", "spar_r"), COL["foam"], (0, 0, 420)),
    ("Boom pylons and pylon bolts", comp("pylon_l", "pylon_r", "pbolts_l", "pbolts_r"), COL["print"], (0, 0, 120)),
    ("Wing joiner and wing bolts", comp("joiner", "wing_bolts"), COL["carbon"], (0, 0, 620)),
    ("Lift booms and clamp caps", comp("boom_l", "boom_r", "caps_l", "caps_r"), COL["carbon"], (0, 0, -160)),
    ("Motor mounts, ESCs and lift motors", comp("mounts_l", "mounts_r", "escs_l", "escs_r", "motors_l", "motors_r"), COL["elec"], (0, 0, -60)),
    ("Landing legs", comp("legclamps_l", "legclamps_r", "legrods_l", "legrods_r", "legfair_l", "legfair_r", "feet_l", "feet_r"), COL["metal"], (0, 0, -330)),
    ("ColdCell packs", comp("packs"), COL["pack"], (0, 0, 330)),
    ("Hatch and GNSS mast", comp("hatch", "gnss"), COL["ply"], (0, 0, 560)),
    ("Lift propellers", comp("props_l", "props_r"), "#374151", (0, 0, 120)),
    ("Heated pitot probe", comp("pitot"), COL["steel"], (-200, 0, 0)),
    ("Payload (1 kg, from the payload's own design)", comp("payload"), "#A8A29E", (300, 0, -480)),
]


def do_overview():
    parts = [Part(n, s, c, None, e) for n, s, c, e in GROUPS]
    overview(parts, OUT / "overview.png", "Kitewright Range: every component, pulled apart and numbered in build order",
             key=True, size=(11, 7))
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

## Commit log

2026-10-03 Kitewright Range at TRL 3: constructable design (kit 1.7.0)
    Problem, concept and requirements; sizing calculations; CAD model, STEP and STL; general arrangement drawing; bill of materials; build plan with making sketches, joint close-ups and step pictures; design decisions register (design choices decided under Amish's 2026-10-03 pre-approval; requirement decisions open for Amish); TRL 2 and TRL 3 review; photoreal renders and storefront card. Private until Amish opens it.
    [bom.csv, kitewright-range-assembly.step, kitewright-range-boom-clamp-caps.stl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]
2026-10-04 Carry Amish's round 2 requirement decisions into the design
    Amish approved all 47 recommendations on 2026-10-03 ("i approve all of the 47 recommendations provided by you. Execute them."). Each repo gains a decision record (DDR-003, or the next free number for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
    [bom.csv, kitewright-range-assembly.step, kitewright-range-boom-clamp-caps.stl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]
2026-10-04 Carry Amish's round-2 and round-3 decisions into the design
    Amish approved all 46 round-2 recommendations ("i agree with all the 46 recommendations you provided. please proceed.") and all round-3 recommendations ("For round 3, I agree with all your proposed r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
    [bom.csv, kitewright-range-assembly.step, kitewright-range-boom-pylon-right.step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]

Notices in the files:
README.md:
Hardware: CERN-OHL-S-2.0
